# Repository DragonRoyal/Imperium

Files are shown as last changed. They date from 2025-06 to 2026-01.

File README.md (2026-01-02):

# Imperium
### An Autonomous, Sensor-Driven Chessboard with Electromagnetic Piece Control

## Abstract

**Imperium** is a fully autonomous chessboard that detects and moves pieces using a precision electromagnetic gantry, per-square Hall-effect sensing, and CNC-style motion control. The system integrates custom mechanical design, multi-PCB electronics, and firmware-level motion planning to deliver seamless, repeatable gameplay without manual calibration.

---

## System Overview

```mermaid
flowchart LR
    Pieces[Chess Pieces — Magnets]
    Sensors[Hall Sensor Matrix — 64 Squares]
    Mux[16:1 Multiplexers]
    MCU[ESP32 Master Controller]
    Drivers[TMC2209 Motor Drivers]
    Motors[Stepper Motors — T-Bot Gantry]
    Magnet[Electromagnet]

    Pieces --> Sensors
    Sensors --> Mux
    Mux --> MCU
    MCU --> Drivers
    Drivers --> Motors
    MCU --> Magnet
```

## Project Media

### Completed System

<p align="center">
  

</p>

<p align="center">
  <em>Figure 2: Fully assembled Imperium chessboard</em>
</p>

### Videos
- 🎥 [demonstration video](https://www.youtube.com/watch?v=dJfiPbZPBKA)
- 🎥 [piece movement](https://www.youtube.com/watch?v=BL-nZTy-D_8)

---

## Hardware Architecture

### Mechanical Subsystem



<p align="center">
  <em>CAD Figure: T-Bot gantry layout and belt routing</em>
</p>

**Gantry Design**
- Type: **T-Bot (CoreXY derivative)**
- Motors: 2× NEMA 17
- Linear motion: 2× MGN12 rails (450 mm)
- Drive: GT2 belts & pulleys
- End effector: Electromagnet (custom mount)

**Design Rationale**
- Compact footprint compared to CoreXY  
- Sufficient precision for chess (no micron-level requirement)  
- Reduced part count and cost  

---

## Sensing Architecture

### Hall Sensor Matrix
```mermaid
flowchart LR
    Square1[Square 1]
    Square2[Square 2]
    SquareN[Square 64]
    Mux1[16:1 MUX]
    MCU[ESP32]

    Square1 --> Mux1
    Square2 --> Mux1
    SquareN --> Mux1
    Mux1 --> MCU
```

<p align="center">
  <em>Figure 5: 64-square Hall-effect sensor grid</em>
</p>

- Sensors: **KTH-1601 (46 Gs threshold)**
- 1 sensor per square (64 total)
- Mounted beneath ~3 mm acrylic

**Why Hall Sensors**
- Instantaneous response  
- No ghosting (unlike reed switches)  
- Reliable removal detection  

---

### PCB Sheet Layout
```mermaid
flowchart TB
    PCB1[Hall PCB Sheet 1\n16 Sensors]
    PCB2[Hall PCB Sheet 2\n16 Sensors]
    PCB3[Hall PCB Sheet 3\n16 Sensors]
    PCB4[Hall PCB Sheet 4\n16 Sensors]
    Master[Master PCB]

    PCB1 --> Master
    PCB2 --> Master
    PCB3 --> Master
    PCB4 --> Master
```
<p align="center">
  
  

</p>

<p align="center">
  <em>Figure 6: Hall sensor PCB sheet (100 mm × 400 mm)</em>
</p>

Each PCB sheet contains:
- 16 Hall sensors  
- 1× 16:1 multiplexer  
- Local decoupling capacitors  
- Ribbon cable interface  

Total sheets: **4**

---

## Control Electronics

### Master Control Board

<p align="center">
  
  
</p>

<p align="center">
  <em>Figure 7: Master PCB functional block diagram</em>
</p>

**Core Components**
- MCU: **ESP32**
- Motor drivers: **2× TMC2209 (UART)**
- Power:
  - 12 V rail (motors + electromagnet)
  - Buck converter → 3.3 V logic
- Electromagnet switching via transistor

All schematics and footprints were custom-designed in KiCad.

---

### UART Motor Control
Chess pieces are moved exclusively along square edges rather than diagonals. This design choice:

Prevents collisions with stationary pieces

Simplifies motion planning

Ensures consistent and predictable movement paths

The gantry executes all moves as a sequence of orthogonal segments.

UART enables:
- Sensorless homing  
- Stall detection  
- Current tuning  
- Advanced diagnostics  

---

### Control Flow

1. **Board State Detection**  
   Hall sensor matrix scans current piece positions.

2. **Move Translation**  
   Chess moves converted into constrained paths.

3. **G-Code Generation**  
   Custom G-code enforces non-diagonal movement.

4. **Execution**  
   G-code executed by **FluidNC** on ESP32.

---

## Bill of Materials (BOM)

<p align="center">
  

</p>

📎 **Full BOM:**  
https://docs.google.com/spreadsheets/d/1yp7t6AiXMwJCAfVlhCX7udocGjks9lOOFWkv4rPJByo/view

---

## Results

- Reliable autonomous gameplay  
- Accurate per-square detection  
- Consistent homing and positioning  
- No recalibration required between games  

---

## Future Work

- Chess engine integration  
- Companion UI / mobile app  
- Faster traversal paths  
- Noise reduction  
- Fully enclosed consumer-ready housing  

---

## References

- CoreXY reference — https://corexy.com  
- Gantry design pitfalls — https://drmrehorst.blogspot.com  

---

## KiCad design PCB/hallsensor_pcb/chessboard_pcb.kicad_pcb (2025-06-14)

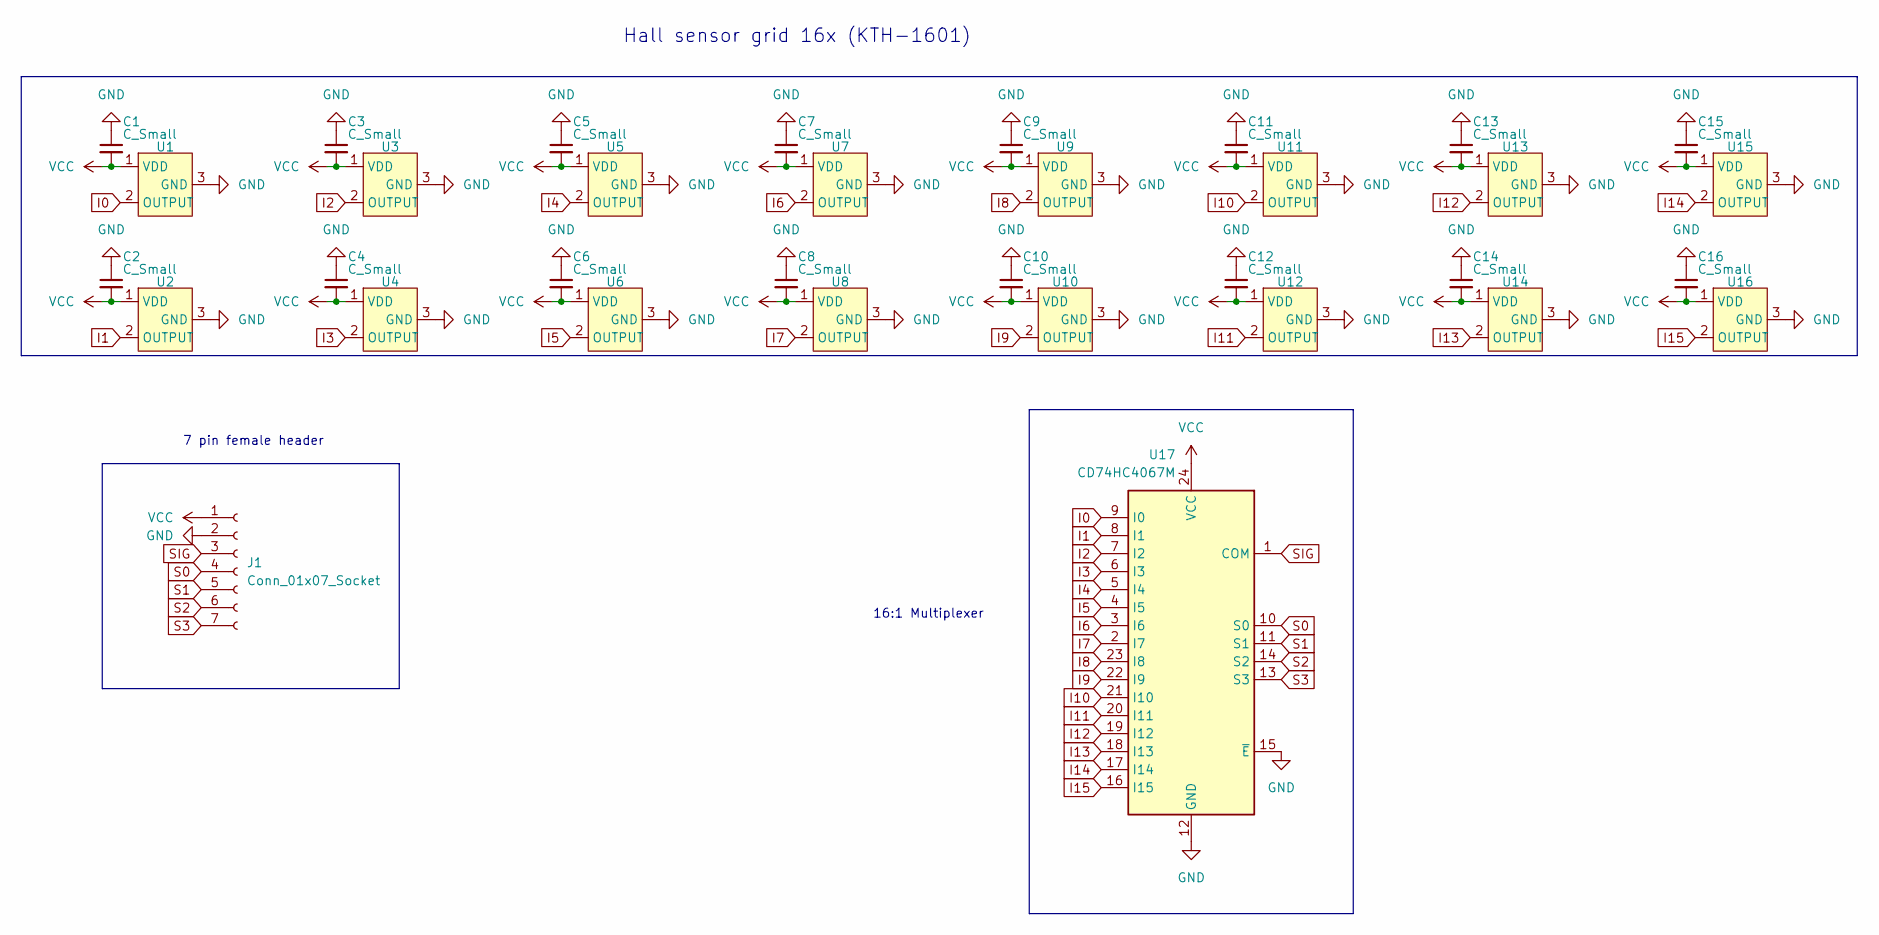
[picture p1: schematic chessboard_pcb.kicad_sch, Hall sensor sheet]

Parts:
C1, C2, C3, C4, C5, C6, C7, C8, C9, C10, C11, C12, C13, C14, C15, C16: C_Small; C_1206_3216Metric_Pad1.33x1.80mm_HandSolder
J1: Conn_01x07_Socket; IDC-Header_2x04_P2.54mm_Vertical
U1, U2, U3, U4, U5, U6, U7, U8, U9, U10, U11, U12, U13, U14, U15, U16: KTH_1601_S3
U17: CD74HC4067M; SOIC-24W_7.5x15.4mm_P1.27mm

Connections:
GND: C1.1, C2.1, C3.1, C4.1, C5.1, C6.1, C7.1, C8.1, C9.1, C10.1, C11.1, C12.1, C13.1, C14.1, C15.1, C16.1, J1.2, U1.3 (GND), U2.3 (GND), U3.3 (GND), U4.3 (GND), U5.3 (GND), U6.3 (GND), U7.3 (GND), U8.3 (GND), U9.3 (GND), U10.3 (GND), U11.3 (GND), U12.3 (GND), U13.3 (GND), U14.3 (GND), U15.3 (GND), U16.3 (GND), U17.12 (GND), U17.15 (~E)
I0: U1.2 (OUTPUT), U17.9 (I0)
I1: U2.2 (OUTPUT), U17.8 (I1)
I2: U3.2 (OUTPUT), U17.7 (I2)
I3: U4.2 (OUTPUT), U17.6 (I3)
I4: U5.2 (OUTPUT), U17.5 (I4)
I5: U6.2 (OUTPUT), U17.4 (I5)
I6: U7.2 (OUTPUT), U17.3 (I6)
I7: U8.2 (OUTPUT), U17.2 (I7)
I8: U9.2 (OUTPUT), U17.23 (I8)
I9: U10.2 (OUTPUT), U17.22 (I9)
I10: U11.2 (OUTPUT), U17.21 (I10)
I11: U12.2 (OUTPUT), U17.20 (I11)
I12: U13.2 (OUTPUT), U17.19 (I12)
I13: U14.2 (OUTPUT), U17.18 (I13)
I14: U15.2 (OUTPUT), U17.17 (I14)
I15: U16.2 (OUTPUT), U17.16 (I15)
S0: J1.4, U17.10 (S0)
S1: J1.5, U17.11 (S1)
S2: J1.6, U17.14 (S2)
S3: J1.7, U17.13 (S3)
SIG: J1.3, U17.1 (COM)
VCC: C1.2, C2.2, C3.2, C4.2, C5.2, C6.2, C7.2, C8.2, C9.2, C10.2, C11.2, C12.2, C13.2, C14.2, C15.2, C16.2, J1.1, U1.1 (VDD), U2.1 (VDD), U3.1 (VDD), U4.1 (VDD), U5.1 (VDD), U6.1 (VDD), U7.1 (VDD), U8.1 (VDD), U9.1 (VDD), U10.1 (VDD), U11.1 (VDD), U12.1 (VDD), U13.1 (VDD), U14.1 (VDD), U15.1 (VDD), U16.1 (VDD), U17.24 (VCC)

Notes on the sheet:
7 pin female header
16:1 Multiplexer
Hall sensor grid 16x (KTH-1601)

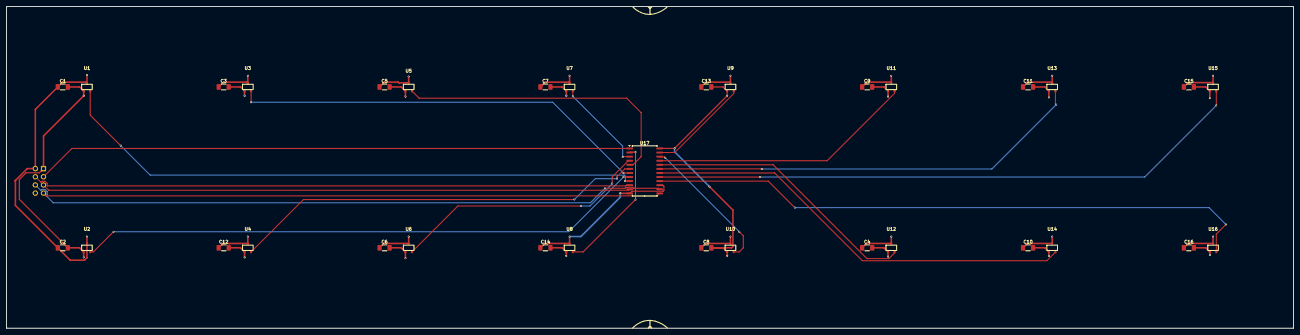
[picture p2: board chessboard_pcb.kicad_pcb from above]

Board: 2 copper layers, 400.0 x 100.0 mm, 34 parts (1 on the bottom side), 23 nets.

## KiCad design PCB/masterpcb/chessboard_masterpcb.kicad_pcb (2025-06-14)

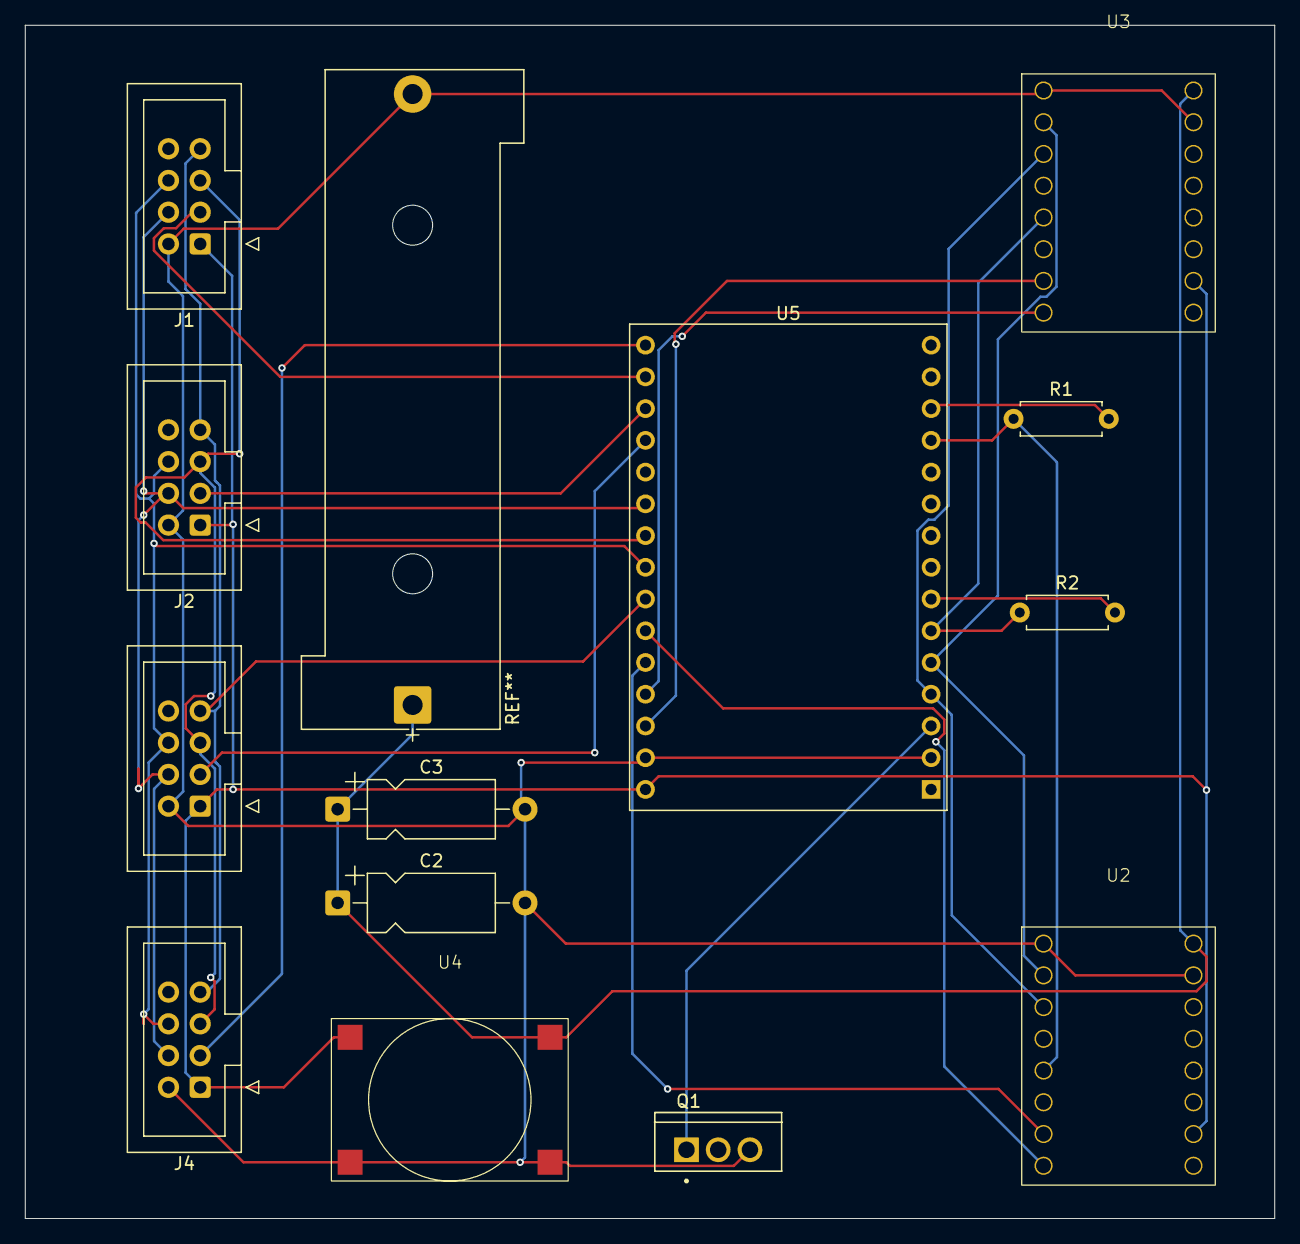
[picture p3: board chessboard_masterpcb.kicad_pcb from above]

Board: 2 copper layers, 100.0 x 95.5 mm, 13 parts (0 on the bottom side), 22 nets.

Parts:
C2, C3: C_Small; CP_Axial_L10.0mm_D4.5mm_P15.00mm_Horizontal
J1, J2, J3, J4: Conn_01x07_Socket; IDC-Header_2x04_P2.54mm_Vertical
Q1: RFP30N06LE; TRANS_RFP30N06LE
R1, R2: R_Small; R_Axial_DIN0207_L6.3mm_D2.5mm_P7.62mm_Horizontal
U2, U3: TMC_2209 Big tree v1.3
U4: MP2303
U5: ESP32-C3-DevKitM-1

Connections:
DIR1: U3.8 (DIR), U5.19 (IO12)
DIR2: U2.8 (DIR), U5.21 (IO27)
GND: C2.2, C3.2, J1.2, J2.2, J3.2, J4.2, Q1.3, U2.1 (EN), U2.10 (GND), U3.1 (EN), U3.10 (GND), U4.2 (IN-), U4.4 (OUT-), U5.2 (GND), U5.17 (GND)
Gate: Q1.1, U5.3 (IO15)
MS1: U2.2 (MS1), U3.2 (MS1), U5.5 (IO4)
MS2: U2.3 (MS2), U3.3 (MS2), U5.4 (IO2)
unnamed: R1.2, U5.13 (TX0)
unnamed: R2.2, U5.7 (TX2)
S0: J1.4, J2.4, J3.4, J4.4, U5.25 (IO32)
S1: J1.5, J2.5, J3.5, J4.5, U5.24 (IO33)
S2: J1.6, J2.6, J3.6, J4.6, U5.23 (IO25)
S3: J1.7, J2.7, J3.7, J4.7, U5.22 (IO26)
SIG1: J4.3, U5.30 (EN)
SIG2: J1.3, U5.29 (IO36)
SIG3: J2.3, U5.28 (IO39)
SIG4: J3.3, U5.27 (IO34)
STEP1: U3.7 (STEP), U5.18 (IO13)
STEP2: U2.7 (STEP), U5.20 (IO14)
UART1: R1.1, U2.5 (USART), U5.12 (RX0)
UART2: R2.1, U3.5 (USART), U5.6 (RX2)
VDD: C2.1, C3.1, U2.9 (VM), U3.9 (VM), U4.1 (IN+)
VDD_3.3: J1.1, J2.1, J3.1, J4.1, U2.15 (VDD), U3.15 (VDD), U4.3 (OUT+), U5.16 (VIN)

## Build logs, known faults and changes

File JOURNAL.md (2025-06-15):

---
title: "Imperium"
author: "Aarav Singhania"
description: "A self moving chessboard controlled by electro magnets"
---
Total Time spent: 37 hours
## **5/24/2025 Log 1 Deciding a Gantry**
Some of the main things I want to keep in mind while deciding a gantry is the cost and the size of the gantry, who wants to play chess on a 5 feet x 5 feet chessboard? 
Before deciding a gantry I wanted to lay out what were the bare minimum requirements my gantry should be able to achieve. 
### *The gantry should:** ###
+ Have high precision ( chess pieces not colliding on each other )
+ Be robust, a chessboard is something that would have belts, motors, pulleys and etc moving all the time, it needs be able to not wear out too soon.
+ Strong enough to support the weight of the electromagnet mechanism
+ High repeatability (be able to return to the same position multiple times
---
**Note**: Precision and repeatability do not need to be on the level of something like a 3D printer for a project such as this. Tolerances can be higher for this gantry as compared to a gantry needed for a 3D printer.

With this information I researched multiple different types of gantries and I landed on the coreXY. A popular and common gantry used in all sorts of projects including 3D printers. Motor control is simple with 2 motors controlling the movement of the gantry, horizontal movement is achieved from both motors spinning in the same direction, vertical by two opposite direction and diagnal movement is done by spinning only one motor.

CoreXy implementation

A corexy gantry is composed of at least 4 pulleys, 2 motors, 3 linear rods ( or guides ) with 2 belts. After picking some choosing some components I designed a implementation of the CoreXy mechanism. I settled on 2 Nema 17 motors and linear rods as my main componenets. I designed 3d printed mounts and pulleys to connect the parts but the implementation had a problem, the gantry was too big, with the COREXY's strengths of  precision and speed was the issue the space needed to accomodate such a large design, my current implementation was already over 600mm width.
yZ1mRqmg0R

After researching different smaller implementations I landed on T-Bot. T-bot is'nt the most common design and you wont see it in designs such as 3D printers because its not necessarily precise or fast enough for a 3D printer but it should work fine for a chessboard. Next session im going to start designing a H-Bot implementation
**Time Spent: 4 hours**

## **5/26/2025 - 5/29/2025 Log 2 Designing my Gantry**
  A T-Bot gantry is really a fork of the coreXY and thus the same principles apply, the belts controlling X and Y direction must be pararell. The design of a T-bot gantry is pretty self explanatory, it looks like a T. The gantry would have 2 linear guides, 2 Nema 17 motors, 8 pulleys and 1 belt. The assembly of this gantry would be more effecient and cheaper since we traded the extra guide and belt for 4 more pulleys. To pick which linear guides I wanted I looked at the specifications and differences between the different MGN## rails. A rail such as MGN12 would be a low profile rail which would handle less load compared to a HGR12. I picked 2 MGN12 Rails which were each 450mm. . The holes on the rail are too far spaced apart to just be directly connected so I made a 3d printed adapter to connect the two rails.

  Now, the hard part is actually making the full gantry with the other parts ( belts, pulleys, motors etc ). I made a wood board frame for the components to be placed on top with holes spaced 25mm apart. The first thing I needed was pieces to connect the linear rails with the wooden board. I designed 3 pieces for the two ends of the rail and the center. . My vision for the implementation of the T-Bot gantry would be this, the red pulleys are idler pulleys and the blue ones being controlled by the motor. My drawing skills arent the best but it gives a general idea of the layout of the gantry, **note** the belts in the actual design would be pararal or else the tension would not be distributed evenly. I decided on small GT2 pulleys and some slightly bigger ones for the ones attached to the motor. I designed a motor mount and pulley mounts in order to hold the moving and idler pulleys. By convention NEMA 17 motors have the same X-Y dimensions so designing a motor mount was easier than I thought. I also had to design a a additional pulley mount to be connected to the guide rails. The biggest thing with the designing of these componenets are the positioning of the pulleys, the belts **must** be parallel. belt offset This is not my sketch but its good for illustrating that even the belt thickness should be taken in account in this case im using a standard 6mm timing belt. After designing all my compoenents and placing them into a assembly I started making a belt but I constantly ran into issues of my belts not being parallel; sometimes a a pulley would be 2 mm displaced from another pulley, or sometimes I didnt take into account belt thickness but after trial and error I ended up with a parallel design ... actually I failed to notice the belts were intersecting through the linear guides. But it was'nt a hard fix and I adjusted all my pulleys a few milimeters higher in order to stop the clipping. I still had a few minor issues in my model, most notably different mates that were not fully defined but after fixing all the errors (I hope) I ended up with a finished product. . I still have a little bit of work left to do on some of the models like the pulley mount but the main design is pretty much done. It took me a span of 2-3 days to design the gantry as I ran into lots of different types of issues I never encountered before but some helpful websites that helped me were 
[basic philoshpy ](https://corexy.com/) and some [common pitfalls when designing a gantry](https://drmrehorst.blogspot.com/2018/08/corexy-mechanism-layout-and-belt.html)
**Time spent: 9 Hours**

## **6/4/2025 Log 3 Making a BOM** ##
  Since parts are accumulating fast and I don't want to lose track of parts I decided to make a BOM with all my parts im currently using. I split my BOM into 4 main parts, Electronics, Hardware, Raw materials and Misc. I decided to also section my BOM off with the type of componenent. A description of it and why I need it, a limk to the part and price by quanitity, quanity and the total price. Because most of my parts are sourced from the same types of manafacturers I added a columm with common manafacturers and totalled up my parts cost with them to save on shipping. Heres a snippet of the general template of the BOM .
Since my chessboard is 490mm x 490mm, instead of having a pcb of that size since it would cost alot I decided to split it up into a 100x400mm pcb, the reason for this is I would be getting 5 boards anyways and now I can use 4 of them saving more money. One thing to note is I did 100x400 instead of 100x500 since the extra 90mm is just the space outside the chess squares. 
I attached a link of my bom [here](https://docs.google.com/spreadsheets/d/1yp7t6AiXMwJCAfVlhCX7udocGjks9lOOFWkv4rPJByo/edit?usp=sharing).
**Time spent 1 hour**

## **6/4/2025 Log 4 Hall sensor and Magnet Work** ##
One of the most important parts of this project is accurate piece detection. There were 2 main implementations I could have done, magnets under each chess pieces with a matrix of reed switches or a hall sensor implementation. I decided to continue with a hall sensor implementation because unlike reed switches they will turn on and off instantly when my piece is removed. Reed switches suffer from ghosting issues where the switch might not close even after the magnets been removed. The type of hall sensor and how many I use is based on the magnet under each chess piece. Any typical N35 Magnet gives around 3000-4000 Gauss of magnetism but the strength of the magnet decreases exponentially, somewhat like a inverse cube. At just a distance of ~25mm the strength can decrease around 97%, from 2000 gauss to 60 gauss. One thing you might be wondering is where did I get the number 2000 from? Well in theory you would expectequal magnectic strength from all sides but a concept called flux leakage exists, the more 'uneven' a magnet is the more gauss can escape into different directions.  This graph is a good representation for the rapid decrease in power over distance. The magnet in the picture is the same as the magnet im currently deciding to use for my chess pieces, a N35 magnet with diameter of 0.7 in and a thickness of 3mm. Some potential issues you might be thinking of is maybe the magnets field overlapping into another square and giving a false positive but because of the rapid loss in magnestism ontop of the fact that the hall sensor will be below a 3mm arylic I dont see that happening. A hall sensor I was researching was the KTH-1601, it has 3 different models in the package a throughole componenet and 2 SMD componenets also with 3 different sensitivity options, 22 Gs Vs 33 Gs Vs 46 Gs. At minimum I would need 64 hall sensors (one for each square) but I might need multiple sensors per square if I run into issues of overlapping but thats a issue which can only reliably be tested once the parts arrive. Due to the large amounts of sensors im using SMD componenets and 46Gs version to reduce issues of overlapping, at a distance of 3mm the gauss is still well over 46 meaning it will still be able to detect.  According to the manafactur datasheet (link [here](https://www.sensor-test.de/assets/Fairs/2024/ProductNews/PDFs/KTH1601-Series-Datasheet.pdf)) the sensor is a binary sensor able to detect both south and north pole using a Schmitt trigger to prevent help with flucating values. Since im having 4 pcbs each 100mm by 400mm that means each pcb can encampass 16 sensors, to make wiring easier im going to use 16:1 multiplexer meaning only 1 muliplexer per pcb and I would only need to use 4 pins on my microcontroller. 
**Time spent 4 hours**
## **6/7/2025 Log 5 PCB for Hall sensor sheet ** ##
My current electrical setup for the chessboard will be 4 pcb sheets (100mm x 400m) with 16 hall sensors, a 16:1 multiplexer and a ribon cable header pins, I will also have a additonal pcb with a microcontroller (have not decided one yet) power regulator and etc to act as the master pcb. My main pcb will connect to my 4 pcb sheets as well as the electro-magnet and 2x nema 16 motors. Im going to first design my pcb sheet since I have already figured out the parts for that. KICAD does not have a symbol nor footprint for the KTH-1601 hall sensor so I learned how to design a simplesymbol (albeit it does not look the best) with the 3 pins needed. 
The datasheet for the KTH-1601 recommend a 1 microfared capicitor near the supply pin in order to reduce noise so I also placed a capacitor near the hall sensor. The general logic of the board is I will have the board powered by the "master board" and because of that Im going to have a 8 pin ribbon connect from the master board to the pcb sheet. The pins are needed for power, ground, data from the mux, and 4 pins are needed for controlling the multiplexer which leaves 1 pin as empty.  Thats the finished schematic I have with all the parts I need for the pcb hall array sheet. Since the KTH-1601 also does'nt have a footprint I designed a simple SMD footprint. I'm deciding to use mainly smd components because the hall sensors and capacitors are over 128 pieces combined and soldering them from hand would take forever, to solder it im going to use a stencil and a hotplate. I spaced all my hall sensors 50mm apart from each other and 25mm away from the edge of the board, I also placed the capaicator close to the hall sensor in order to be more effective.
  All my boards are connected by ribbon wires so I added a 8 pin header on the side of the board and on the bottom layer, I placed it on the bottom layer since its thick and it might have been harder to install the pcb into the chessboard if it was on the top. I also placed the multiplexer in the middle. Since most my componenents were SMD I didnt really need the bottom layer so I turned the bottom layer into a VCC and ground plane. I used vias in order to convert from the top and bottom layer in order the access the ground/vcc plane, I saved some extra wiring from doing this too. To make wiring more effecient I also placed vias to switch from bottom and top layer to reduce the amount of traces near the multiplexer. With that, I finished my wiring of the board  
**Time spent: 5 hours**

## ** 6/12/2025 Log 6 Code/Board logic ** ##
Before I started working on my board further I wanted to make sure the general logic of the board is decided. What I mean by that is my main objective of the board is to able to play chess against the user as seamlessly as possible, the user should not be having to debug or go through the mistakes the bot may make. One thing I wanted to get figured out was the homing of the bot, if the chessboard starts at a random position it will mistakenly think of that position as (0,0) which will make it go out of bounds and place pieces in the wrong place. To fix it I could use encoders or sensors in order to go to "true" 0,0 but a easier approach would be just to use the sensorless homing feature present in the TMC2209 motor driver. Sensorless homing does exactly what it sounds, it can home the bot to the correct position without the use of external sensors, it does this by moving the gantry in small increments until it hits a physical hardstop and the motor starts stalling at which point the driver knows the position of the bot and it can send that information back to the MCU in order to go back to 0,0.  One thing to note is sensorless homing as well as some of the other advanced features provided by the TMC are only available through the UART protocol. Motor movement and direction are through the STEP and DIR pins and motor configuration through the UART pin.
Another major headache is figuring out motor movement, since my gantry does not have dedicated motors one for X movement and one for Y movement I need to be able to find a effective way of moving the robot from 1 square to another. Another thing is my gantry can not move in diagonals, I need a custom movement system. If I moved in diagnols pieces would collide with each other. I need to move in the edges of each square. 

Researching different implementations of a movement system I found G-code to motor movement pretty much for example what klipper does. I would generate custom G-Code depending on the intital square and the end square in pythonn I would then feed that into a firmware called FluidNc a G-Code to motor movement application common in many CNC's. This approach would be similar to klipper in 3D printers but the reason I didn't use klipper is because its not supported on ESP32's and I would rather use a more light weight firmware rather than one packed with features that I would barely use. I'm going to work on the code once I finish manafacturing my actual board but I wanted to first get a sense of what I would need to code and if I needed any extra sensors on my board. Its better to research and find out now then make my board and realize then.
**Time Spent: 4 Hours**

## ** 6/13/2025 Log 7 Master Board ** ##
Earlier I made 4 PCB sheets with hall sensors but to control them I need to make a master board. My master board would be what controls the whole board, it would have a ESP32 as the MCU, a 12 volt battery for the Electromagnet and the 2 motors, a buck converter (12V to 3.3V) for the ESP32 and the hall sensors, 2x TMC2209 motor drivers, 4x of 8 pin headers in order to connect to the other 4 boards and a transistor to turn the electro-magnet off and on. Many of these parts do not have footprints or schematics so I designed footprints and schematics for the buck converter the motor drivers and the esp32. 
I started working on the schematic of the board but because im new to the UART protocol I looked into the datasheet and learned more about the correct implementation and the function of each pin on their [datasheet](https://www.analog.com/media/en/technical-documentation/data-sheets/tmc2209_datasheet_rev1.09.pdf). I learned that you should connect both your MCU's uart pins to the motor driver one and be using a resistor in order to allow for bidirectonal data, it allow allows the manafactur to only need 1 pin. One more thing I did was add a 100uF capacitor near ground and vcc since it would help with voltage spikes as motors are notirious for voltage spikes. I found a transistor that turns on and off with only a 3.3v and connected that to my electromagnet to act as a gate. I then added my buck converter in order to convert the voltage into something the MCU and hall sensors could use, to connect to the other 4 pcb sheets I added my header pins as well 
For my layout I just arranged my components to fit within a 100x100 pcb and routed it. 

**Time Spent 4 Hours**

## 6/14/2025 Log 8 Updating CAD and BOM** ##
I added lots of new parts since last time I worked on the CAD so I wanted to update it to be reflective of the changes. The first thing im going to design is a electromagnet holder in order to house the elctromagnet, it will be attached to the gantry through 2 counter sink screws 
I also increased the size of the top panel of the chessboard in order to cover the entire 590mm by 590mm chessboard. I also added physical endstops to the pulleys to help with sensorless homing, I imported the electronic components onto the board such as the 4 hall sensor sheets and the master PCB, added a physicalo enclosure around the board and added screw holes to hold the enclosure together. I ran into some issues of parts not fitting and I had to move some parts in order to make space but in the end I ended up with a hopefully finished cad  
**Time spent 3 hours**

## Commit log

2026-01-02 Revise CAD figure caption in README
    Updated the caption for the CAD figure in the README.
2026-01-02 Delete Electromagnet Assembly details from README
    Removed the Electromagnet Assembly section from the README.
2026-01-02 Update images and BOM link in README.md
